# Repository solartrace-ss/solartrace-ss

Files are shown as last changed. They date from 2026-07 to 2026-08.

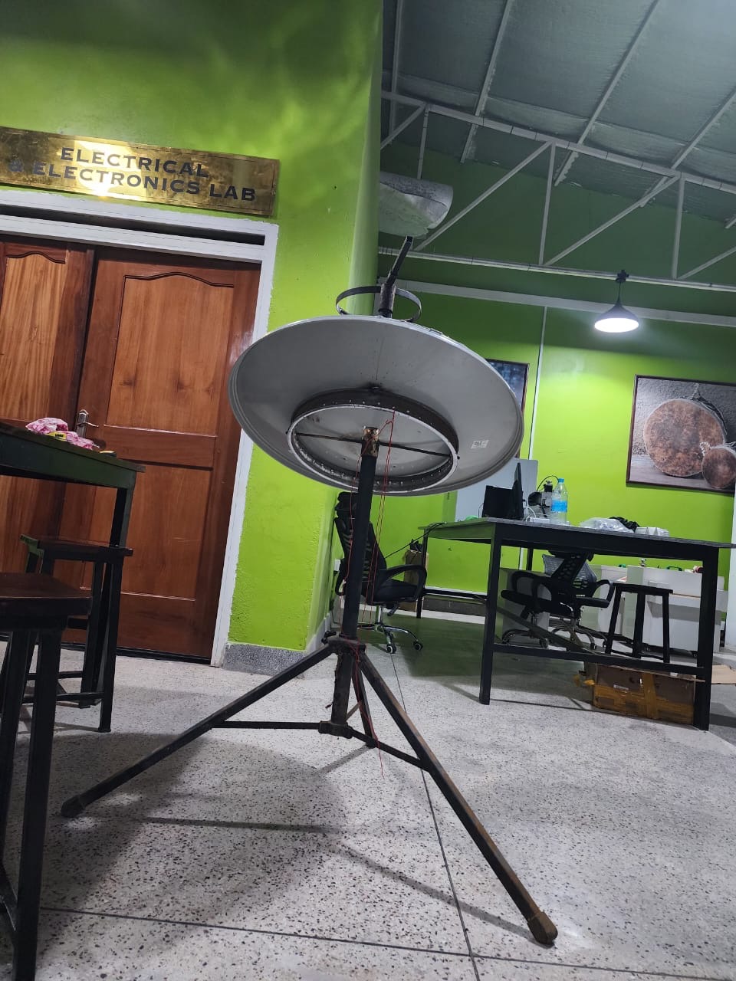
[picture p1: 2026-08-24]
89f00b60-d103-490d-b4b3-06a293f4bbff.jpeg

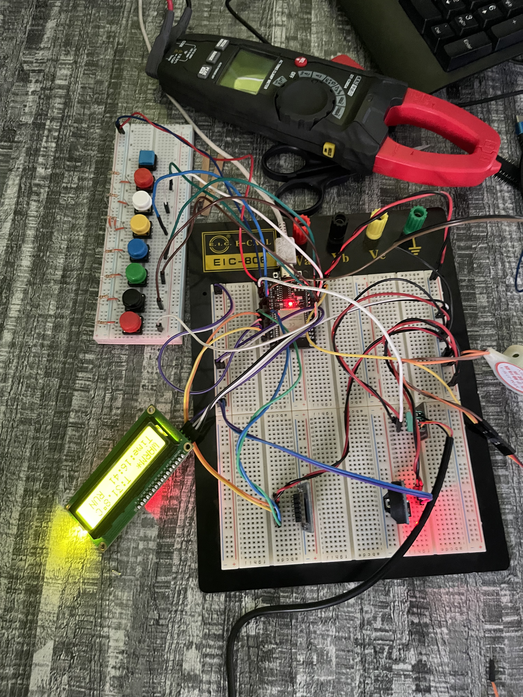
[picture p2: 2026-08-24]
docs/Week5_Submission/Images/IMG_5650.jpeg

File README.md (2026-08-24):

# ☀️ SolarTrace - Smart Solar Cooking for South Sudan

**UbuntuNet Alliance Women Hackathon 2026 | Phase I - Week 1**

## Project Overview
SolarTrace is a smart IoT-connected solar cooker with automatic sun tracking for rural communities in South Sudan.

## The Problem
- 7% electricity access rate
- >80% households depend on biomass
- 4-6 hours daily fuel collection
- ~20% forest cover loss since 2000

## Our Solution
- RTC-based automatic sun tracking (10-minute intervals)
- Blynk IoT platform integration
- Four cooking modes (cooking, sterilization, boiling, warming)
- Safety mechanism (130°C shutdown)
- SD card data logging

## Team
- Alek Madut Malual - Lead Developer
- Clementina Agiu Gual Koch - UI/UX & Documentation
- Abuk Santino Garang Chan - Testing & Logistics

## Week 1 Submission
 [South_Sudan_SOLARTRACE_Chapter_One.pdf](docs/Week1_Submission/South_SUdan_SOLARTRACE_Chapter_One.pdf)
## Week 2 Submission
 [South_Sudan_SOLARTRACE_Chapter_Two.pdf](docs/Week2_Submission/South_Sudan_SOLARTRACE_Chapter_Two.pdf)
## Week 3 Submission
 [South_Sudan_SOLARTRACE_Week_3_Progress_Report.pdf](docs/Week3_Submission/Week_3_Progress_Report.pdf)
## Week 4 Submission
 [South_Sudan_SOLARTRACE_Week_4_Week_4_Progress_Report.md](docs/Week4_Submission/Week_4_Progress_Report.md)
## Week 5 Submission
 [South_Sudan_SOLARTRACE_Week_5_Week_5_Progress_Report.md](docs/Week5_Submission/Week_5_Progress_Report.md)

## License
MIT

---
*Harnessing the sun for a sustainable future.*

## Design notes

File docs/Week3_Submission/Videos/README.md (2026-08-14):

[Download W3out.mp4 directly](https://raw.githubusercontent.com/solartrace-ss/solartrace-ss/main/docs/Week3_Submission/Videos/W3out.mp4)

[Download RTC_Connection.mp4 directly](https://raw.githubusercontent.com/solartrace-ss/solartrace-ss/main/docs/Week3_Submission/Videos/RTC_Connection.mp4)

[Download RTC_Test.mp4 directly](https://raw.githubusercontent.com/solartrace-ss/solartrace-ss/main/docs/Week3_Submission/Videos/RTC_Test.mp4)

[Download Servo_Test.mp4 directly](https://raw.githubusercontent.com/solartrace-ss/solartrace-ss/main/docs/Week3_Submission/Videos/Servo_Test.mp4)

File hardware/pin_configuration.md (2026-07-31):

# SolarTrace - ESP32 Pin Configuration

## Complete Pin Mapping for SolarTrace System

---

## 1. Pin Configuration Summary

```
┌────────────────────────────────────────────────────────────────────────────────────────┐
│                                                                                        │
│                         SOLARTRACE - ESP32 PIN CONFIGURATION                           │
│                                                                                        │
│  ┌─────────────────────────────────────────────────────────────────────────────────┐   │
│  │                                                                                 │   │
│  │  ┌──────────────────────────────────────────────────────────────────────────┐   │   │
│  │  │                                                                          │   │   │
│  │  │                               ESP32-WROOM-32                             │   │   │
│  │  │                                                                          │   │   │
│  │  │  ┌───────────────────────────────────────────────────────────────────┐   │   │   │
│  │  │  │                                                                   │   │   │   │
│  │  │  │   ┌─────┐  ┌─────┐  ┌─────┐  ┌─────┐  ┌─────┐  ┌─────┐  ┌─────┐   │   │   │   │
│  │  │  │   │     │  │     │  │     │  │     │  │     │  │     │  │     │   │   │   │   │
│  │  │  │   │ 3V3 │  │ EN  │  │ VP  │  │ VN  │  │ D34 │  │ D35 │  │ D32 │   │   │   │   │
│  │  │  │   │     │  │     │  │     │  │     │  │     │  │     │  │     │   │   │   │   │
│  │  │  │   └─────┘  └─────┘  └─────┘  └─────┘  └─────┘  └─────┘  └─────┘   │   │   │   │
│  │  │  │   ┌─────┐  ┌─────┐  ┌─────┐  ┌─────┐  ┌─────┐  ┌─────┐  ┌─────┐   │   │   │   │
│  │  │  │   │     │  │     │  │     │  │     │  │     │  │     │  │     │   │   │   │   │
│  │  │  │   │ D33 │  │ D25 │  │ D26 │  │ D27 │  │ D14 │  │ D12 │  │ D13 │   │   │   │   │
│  │  │  │   │     │  │     │  │     │  │     │  │     │  │     │  │     │   │   │   │   │
│  │  │  │   └─────┘  └─────┘  └─────┘  └─────┘  └─────┘  └─────┘  └─────┘   │   │   │   │
│  │  │  │   ┌─────┐  ┌─────┐  ┌─────┐  ┌─────┐  ┌─────┐  ┌─────┐  ┌─────┐   │   │   │   │
│  │  │  │   │     │  │     │  │     │  │     │  │     │  │     │  │     │   │   │   │   │
│  │  │  │   │ D9  │  │ D10 │  │ D11 │  │ D5  │  │ D6  │  │ D7  │  │ D8  │   │   │   │   │
│  │  │  │   │     │  │     │  │     │  │     │  │     │  │     │  │     │   │   │   │   │
│  │  │  │   └─────┘  └─────┘  └─────┘  └─────┘  └─────┘  └─────┘  └─────┘   │   │   │   │
│  │  │  │   ┌─────┐  ┌─────┐  ┌─────┐  ┌─────┐  ┌─────┐  ┌─────┐  ┌─────┐   │   │   │   │
│  │  │  │   │     │  │     │  │     │  │     │  │     │  │     │  │     │   │   │   │   │
│  │  │  │   │ D15 │  │ D16 │  │ D0  │  │ D1  │  │ D2  │  │ D3  │  │ D4  │   │   │   │   │
│  │  │  │   │     │  │     │  │     │  │     │  │     │  │     │  │     │   │   │   │   │
│  │  │  │   └─────┘  └─────┘  └─────┘  └─────┘  └─────┘  └─────┘  └─────┘   │   │   │   │
│  │  │  │   ┌─────┐  ┌─────┐  ┌─────┐  ┌─────┐  ┌─────┐  ┌─────┐  ┌─────┐   │   │   │   │
│  │  │  │   │     │  │     │  │     │  │     │  │     │  │     │  │     │   │   │   │   │
│  │  │  │   │ D5  │  │ D18 │  │ D19 │  │ D21 │  │ RX0 │  │ TX0 │  │ D22 │   │   │   │   │
│  │  │  │   │     │  │     │  │     │  │     │  │     │  │     │  │     │   │   │   │   │
│  │  │  │   └─────┘  └─────┘  └─────┘  └─────┘  └─────┘  └─────┘  └─────┘   │   │   │   │
│  │  │  │   ┌─────┐  ┌─────┐  ┌─────┐  ┌─────┐  ┌─────┐  ┌─────┐  ┌─────┐   │   │   │   │
│  │  │  │   │     │  │     │  │     │  │     │  │     │  │     │  │     │   │   │   │   │
│  │  │  │   │ D23 │  │ D24 │  │ D25 │  │ D26 │  │ D27 │  │ D32 │  │ D33 │   │   │   │   │
│  │  │  │   │     │  │     │  │     │  │     │  │     │  │     │  │     │   │   │   │   │
│  │  │  │   └─────┘  └─────┘  └─────┘  └─────┘  └─────┘  └─────┘  └─────┘   │   │   │   │
│  │  │  │   ┌─────┐  ┌─────┐  ┌─────┐  ┌─────┐  ┌─────┐  ┌─────┐  ┌─────┐   │   │   │   │
│  │  │  │   │     │  │     │  │     │  │     │  │     │  │     │  │     │   │   │   │   │
│  │  │  │   │ D34 │  │ D35 │  │ VN  │  │ VP  │  │ EN  │  │ GND │  │ VIN │   │   │   │   │
│  │  │  │   │     │  │     │  │     │  │     │  │     │  │     │  │     │   │   │   │   │
│  │  │  │   └─────┘  └─────┘  └─────┘  └─────┘  └─────┘  └─────┘  └─────┘   │   │   │   │
│  │  │  │                                                                   │   │   │   │
│  │  │  └───────────────────────────────────────────────────────────────────┘   │   │   │
│  │  │                                                                          │   │   │
│  │  └──────────────────────────────────────────────────────────────────────────┘   │   │
│  │                                                                                 │   │
│  └─────────────────────────────────────────────────────────────────────────────────┘   │
│                                                                                        │
└────────────────────────────────────────────────────────────────────────────────────────┘
```

---

## 2. Detailed Pin Configuration Table

| #  | ESP32 Pin | Label | Function | Connected To | Component | Wire Color | Notes |
|----|---|---|---|---|---|---|---|
| 1  | 3.3V | 3.3V  | Power Output | VCC | DS3231 RTC | RED | 3.3V Power |
| 2  | 3.3V | 3.3V  | Power Output | VCC | MAX6675 | RED | 3.3V Power |
| 3  | 3.3V | 3.3V  | Power Output | VCC | MicroSD | RED | 3.3V Power |
| 4  | VIN | 5V | Power Input | VCC | MG995 Servo | RED | 5V Power |
| 5  | GND | GND | Ground | GND | DS3231 RTC | BLACK | Common Ground |
| 6  | GND | GND | Ground | GND | MAX6675 | BLACK | Common Ground |
| 7  | GND | GND | Ground | GND | MG995 Servo | BLACK | Common Ground |
| 8  | GND | GND | Ground | GND | MicroSD | BLACK | Common Ground |
| 9  | GND | GND | Ground | GND | Pull-up Resistors | BLACK | Common Ground |
| 10 | GPIO21 | 21 | I2C Data (SDA)  | SDA | DS3231 RTC | GREEN | I2C Communication |
| 11 | GPIO22 | 22 | I2C Clock (SCL) | SCL | DS3231 RTC | BLUE | I2C Communication |
| 12 | GPIO13 | 13 | PWM Output | Signal | MG995 Servo | ORANGE | Servo Control |
| 13 | GPIO15 | 15 | SPI Chip Select | CS | MAX6675 | YELLOW | SPI Communication |
| 14 | GPIO14 | 14 | SPI Clock | SCK | MAX6675 | WHITE | SPI Communication |
| 15 | GPIO12 | 12 | SPI Data Out | SO | MAX6675 | PURPLE | SPI Communication |
| 16 | GPIO5 | 5 | SPI Chip Select | CS | MicroSD | YELLOW | SPI Communication |
| 17 | GPIO18 | 18 | SPI Clock | SCK | MicroSD | WHITE | SPI Communication |
| 18 | GPIO23 | 23 | SPI Master Out  | MOSI | MicroSD | BLUE | SPI Communication |
| 19 | GPIO19 | 19 | SPI Master In | MISO | MicroSD | PURPLE | SPI Communication |

---

## 3. Pin Function Grouping

### 3.1 Power Pins

| Pin | Type | Voltage | Current | Usage |
|---|---|---|---|---|
| **3.3V** | Output | 3.3V | 600mA max | RTC, MAX6675, SD Card |
| **VIN**  | Input  | 5V | 2A max | Servo Motor, Battery Input |
| **GND**  | Ground | 0V | - | All components |

### 3.2 I2C Pins

| Pin | Function | Component  | Speed  | Notes |
|---|---|---|---|---|
| **GPIO21** | SDA (Data)  | DS3231 RTC | 100kHz | 4.7kΩ Pull-up Required |
| **GPIO22** | SCL (Clock) | DS3231 RTC | 100kHz | 4.7kΩ Pull-up Required |

### 3.3 SPI Pins

| Pin | Function | Component 1 | Component 2 | Speed | Notes |
|---|---|---|---|---|---|
| **GPIO15** | CS | MAX6675 | - | 4MHz  | Chip Select |
| **GPIO14** | SCK | MAX6675 | MicroSD | 4MHz  | Shared Clock |
| **GPIO12** | SO/MISO  | MAX6675 | MicroSD | 4MHz  | Data Out / Data In |
| **GPIO5**  | CS | - | MicroSD | 4MHz  | Chip Select |
| **GPIO23** | MOSI | - | MicroSD | 4MHz  | Master Out |
| **GPIO19** | MISO | - | MicroSD | 4MHz  | Master In |

### 3.4 PWM Pin

| Pin | Function | Component | Frequency | Duty Cycle | Notes |
|---|---|---|---|---|---|
| **GPIO13** | PWM | MG995 Servo | 50Hz | 5-10% | 1ms=0°, 2ms=180° |

---

## 4. Pull-up Resistor Configuration

### 4.1 I2C Pull-up Resistors

```
┌─────────────────────────────────────────────────────────────────────────┐
│                                                                         │
│                       I2C PULL-UP RESISTOR CONFIGURATION                │
│                                                                         │
│  ┌──────────────────────────────────────────────────────────────────┐   │
│  │                                                                  │   │
│  │    ESP32 3.3V ────────┬──────────────────────────────────────┐   │   │
│  │                       │                                      │   │   │
│  │                       │                                      │   │   │
│  │                       ▼                                      │   │   │
│  │                  ┌─────────┐                                 │   │   │
│  │                  │ 4.7kΩ   │                                 │   │   │
│  │                  └─────────┘                                 │   │   │
│  │                       │                                      │   │   │
│  │                       ├─────────────── GPIO21 (SDA)          │   │   │
│  │                       │                                      │   │   │
│  │                       │                                      │   │   │
│  │                       │                                      │   │   │
│  │    ESP32 3.3V ────────┼──────────────────────────────────┐   │   │   │
│  │                       │                                  │   │   │   │
│  │                       ▼                                  │   │   │   │
│  │                  ┌─────────┐                             │   │   │   │
│  │                  │ 4.7kΩ   │                             │   │   │   │
│  │                  └─────────┘                             │   │   │   │
│  │                       │                                  │   │   │   │
│  │                       ├─────────────── GPIO22 (SCL)      │   │   │   │
│  │                       │                                  │   │   │   │
│  │                       │                                  │   │   │   │
│  │                       ▼                                  │   │   │   │
│  │                    ESP32 GND                             │   │   │   │
│  │                                                          │   │   │   │
│  └──────────────────────────────────────────────────────────┘   │   │   │
│                                                                 │   │   │
└─────────────────────────────────────────────────────────────────────────┘
```

### 4.2 Resistor Specifications

| Resistor | Value | Tolerance | Power | Package | Purpose |
|---|---|---|---|---|---|
| R1 | 4.7kΩ | ±5% | 0.25W | Through-hole | SDA Pull-up |
| R2 | 4.7kΩ | ±5% | 0.25W | Through-hole | SCL Pull-up |

---

## 5. Voltage Level Compatibility

| Component | Logic Level | ESP32 Level | Compatible | Notes |
|---|---|---|---|---|
| **DS3231 RTC**  | 3.3V | 3.3V |  Yes | Direct connection |
| **MAX6675** | 3.3V | 3.3V |  Yes | Direct connection |
| **MG995 Servo** | 5V (Signal) | 3.3V |  Partial | Signal may need level shifting |
| **MicroSD** | 3.3V | 3.3V |  Yes | Direct connection |

### 5.1 Servo Signal Level Shifting (Recommended)

```
┌───────────────────────────────────────────────────────────────────────┐
│                                                                       │
│                     SERVO SIGNAL LEVEL SHIFTER (OPTIONAL)             │
│                                                                       │
│  ┌────────────────────────────────────────────────────────────────┐   │
│  │                                                                │   │
│  │                        ┌────────────────────────────────────┐  │   │
│  │                        │           Logic Level Converter    │  │   │
│  │                        │  ┌──────────────────────────────┐  │  │   │
│  │                        │  │  3.3V Side          5V Side  │  │  │   │
│  │                        │  │                              │  │  │   │
│  │  ESP32 GPIO13 ───────┼─┤  LV1 ──────────────── HV1 ──────┼──┼──────┼─── MG995 Signal
│  │                        │  │  GND                 GND     │  │  │   │
│  │                        │  │  3.3V                HV      │  │  │   │
│  │                        │  │  EN                  EN      │  │  │   │
│  │                        │  └──────────────────────────────┘  │  │   │
│  │                        └────────────────────────────────────┘  │   │
│  │                                                                │   │
│  └────────────────────────────────────────────────────────────────┘   │
│                                                                       │
└───────────────────────────────────────────────────────────────────────┘
```

---

## 6. ESP32 Pin Characteristics

### 6.1 Input/Output Characteristics

| Parameter | Value | Notes |
|---|---|---|
| **Input Voltage (High)**  | 0.75 × VDD | Minimum 2.4V for 3.3V supply |
| **Input Voltage (Low)** | 0.25 × VDD | Maximum 0.8V for 3.3V supply |
| **Output Voltage (High)** | 0.8 × VDD  | Minimum 2.64V for 3.3V supply |
| **Output Voltage (Low)**  | 0.1 × VDD  | Maximum 0.33V for 3.3V supply |
| **Output Current (Max)**  | 40mA | Per GPIO pin |
| **Pull-up Resistor** | 45kΩ | Internal, can be enabled/disabled |

### 6.2 Pin Capacities

| Pin Type | Count | Max Current | Notes |
|---|---|---|---|
| **GPIO** | 34 | 40mA | General purpose |
| **Analog Input** | 18 | - | ADC1 and ADC2 |
| **PWM** | 16 | - | LEDC channels |
| **I2C** | 2 | - | SDA and SCL |
| **SPI** | 2 | - | VSPI and HSPI |
| **UART** | 3 | - | Serial communication |

---

## 7. Pin Usage Summary

### 7.1 Used Pins

```
┌──────────────────────────────────────────────────────────────────────────────────────────┐
│                                                                                          │
│                              USED PINS SUMMARY                                           │
│                                                                                          │
│  ┌───────────────────────────────────────────────────────────────────────────────────┐   │
│  │                                                                                   │   │
│  │  Pin     │ Function      │ Component     │ Status                                 │   │
│  │  ──────────────────────────────────────────────────────────────────────────────── │   │
│  │  3.3V    │ Power         │ All (3.3V)    │ Used                                   │   │
│  │  VIN     │ Power         │ Servo (5V)    │ Used                                   │   │
│  │  GND     │ Ground        │ All           │ Used                                   │   │
│  │  GPIO21  │ I2C SDA       │ DS3231 RTC    │ Used                                   │   │
│  │  GPIO22  │ I2C SCL       │ DS3231 RTC    │ Used                                   │   │
│  │  GPIO13  │ PWM           │ MG995 Servo   │ Used                                   │   │
│  │  GPIO15  │ SPI CS        │ MAX6675       │ Used                                   │   │
│  │  GPIO14  │ SPI SCK       │ MAX6675       │ Used                                   │   │
│  │  GPIO12  │ SPI SO        │ MAX6675       │ Used                                   │   │
│  │  GPIO5   │ SPI CS        │ MicroSD       │ Used                                   │   │
│  │  GPIO18  │ SPI SCK       │ MicroSD       │ Used                                   │   │
│  │  GPIO23  │ SPI MOSI      │ MicroSD       │ Used                                   │   │
│  │  GPIO19  │ SPI MISO      │ MicroSD       │ Used                                   │   │
│  │                                                                                   │   │
│  └───────────────────────────────────────────────────────────────────────────────────┘   │
│                                                                                          │
└──────────────────────────────────────────────────────────────────────────────────────────┘
```

### 7.2 Available Pins

```
┌────────────────────────────────────────────────────────────────────────────────────────┐
│                                                                                        │
│                            AVAILABLE PINS                                              │
│                                                                                        │
│  ┌─────────────────────────────────────────────────────────────────────────────────┐   │
│  │                                                                                 │   │
│  │  Pin     │ Function           │ Status           │ Notes                        │   │
│  │  ────────────────────────────────────────────────────────────────────────────── │   │
│  │  GPIO0   │ General Purpose    │ Available      │ Boot mode (Low = Download)     │   │
│  │  GPIO1   │ UART0 TX           │ Available      │ Serial Monitor                 │   │
│  │  GPIO2   │ General Purpose    │ Available      │ Internal pull-up               │   │
│  │  GPIO3   │ UART0 RX           │ Available      │ Serial Monitor                 │   │
│  │  GPIO4   │ General Purpose    │ Available      │                                │   │
│  │  GPIO9   │ General Purpose    │ Available      │                                │   │
│  │  GPIO10  │ General Purpose    │ Available      │                                │   │
│  │  GPIO11  │ General Purpose    │ Available      │                                │   │
│  │  GPIO16  │ General Purpose    │ Available      │                                │   │
│  │  GPIO17  │ General Purpose    │ Available      │                                │   │
│  │  GPIO25  │ General Purpose    │ Available      │                                │   │
│  │  GPIO26  │ General Purpose    │ Available      │                                │   │
│  │  GPIO27  │ General Purpose    │ Available      │                                │   │
│  │  GPIO32  │ General Purpose    │ Available      │                                │   │
│  │  GPIO33  │ General Purpose    │ Available      │                                │   │
│  │  GPIO34  │ Input Only         │ Available      │ No internal pull-up/pull-down  │   │
│  │  GPIO35  │ Input Only         │ Available      │ No internal pull-up/pull-down  │   │
│  │  GPIO36  │ Input Only         │ Available      │ No internal pull-up/pull-down  │   │
│  │  GPIO39  │ Input Only         │ Available      │ No internal pull-up/pull-down  │   │
│  │                                                                                 │   │
│  └─────────────────────────────────────────────────────────────────────────────────┘   │
│                                                                                        │
└────────────────────────────────────────────────────────────────────────────────────────┘
```

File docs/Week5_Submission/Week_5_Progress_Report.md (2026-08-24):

# SolarTrace - Week 5 Progress Report

## UbuntuNet Alliance Women Hackathon 2026

**Project:** SolarTrace - Smart IoT-Connected Solar Cooker  
**Team:** Reffgga Repent Ritti, Clementina Agiu Gual Koch, Abuk Santino Garang Chan  
**Report Period:** Week 5 (August 17-21, 2026)  
**Date:** August 21, 2026

---

## Table of Contents

1. [Executive Summary](#1-executive-summary)
2. [Hardware Development & Integration](#2-hardware-development--integration)
3. [Software Development & Upgrades](#3-software-development--upgrades)
4. [Hackathon Submission & Review](#4-hackathon-submission--review)
5. [Software Testing Results](#5-software-testing-results)
6. [Hardware Assembly Summary](#6-hardware-assembly-summary)
7. [Development Challenges & Solutions](#7-development-challenges--solutions)
8. [Week 5 Deliverables](#8-week-5-deliverables)
9. [Team Contributions](#9-team-contributions---week-5)
10. [System Component Updates](#10-system-component-updates)
11. [Code Repository Updates](#11-code-repository-updates)
12. [Summary of Key Achievements](#12-summary-of-key-achievements)
13. [Software Completion Status](#13-software-completion-status)
14. [Photos & Visual Documentation](#14-photos--visual-documentation)
15. [Next Steps](#15-next-steps-week-6)
16. [Conclusion](#16-conclusion)

---

## 1. Executive Summary

This report documents the progress made during Week 5 (August 17-21, 2026) of the SolarTrace project development. The team focused on hardware integration, system assembly, software upgrades, and final submission preparation. Major milestones achieved include complete hardware assembly with stand, mirror installation, solar panel integration, and successful system testing. The team also participated in a critical hackathon meeting with mentors and submitted all required deliverables including the prototype documentation, PowerPoint presentation, and demo video.

---

## 2. Hardware Development & Integration

### 2.1 Stand Construction & Assembly

| Component | Work Done | Result | Remarks |
|---|---|---|---|
| Stand Structure | Welding and assembly of support frame | Complete | Stable and level structure |
| Tracking Level | Alignment calibration for sun tracking | Complete | Accurate horizontal/vertical positioning |
| Burner Ring (Pot Receptacle) | Fabrication and mounting | Complete | Securely holds cooking vessel |

**Details:**
- The stand was welded to provide a sturdy base for the parabolic dish
- Tracking level was calibrated to ensure precise sun tracking
- The burner ring (pot receptacle) was fabricated and securely mounted to hold cooking vessels

### 2.2 Parabolic Dish Mirror Installation

| Task | Details | Result |
|---|---|---|
| Mirror Installation | Mirror pieces stuck onto parabolic dish | Complete |
| Reflectivity Test | Tea making test conducted | PASS |
| Focal Point Alignment | Verified focal point for cooking | Accurate |

**Testing Results:**
- **Tea Making Test:** Successfully boiled water and made tea using solar energy
- **Temperature Achieved:** Reached cooking temperature within expected time
- **Focal Point:** Accurately concentrated sunlight on the burner ring

### 2.3 Solar Panel Integration

| Component | Specification | Status |
|---|---|---|
| Solar Panels | 50W panels | Added |
| Panel Mounting | Securely mounted on stand | Complete |
| Connection | Connected to charge controller | Complete |
| Power Output | Verified charging capability | PASS |

**Benefits of Solar Panel Addition:**
- Provides sustainable power for electronics
- Reduces reliance on batteries
- Extends system operational time
- Supports off-grid operation

---

## 3. Software Development & Upgrades

### 3.1 Component Testing on ESP32

| Component | Previous | Updated/Tested | Result |
|---|---|---|---|
| RTC Module | DS3231 | Tested on ESP32 | PASS |
| Motor | MG995 Servo | Tested on ESP32 | PASS |
| Temperature Sensor | MAX6675 | Changed to DS18B20 | PASS |
| Buzzer | - | Newly added and tested | PASS |
| LCD Module | I2C LCD | Tested on ESP32 | PASS |

### 3.2 Sensor Migration: MAX6675 → DS18B20

| Aspect | MAX6675 (Previous) | DS18B20 (New) | Reason for Change |
|---|---|---|---|
| Interface | SPI | 1-Wire | Simplified wiring |
| Accuracy | +/- 0.5°C | +/- 0.5°C | Comparable accuracy |
| Power | 3.3V/5V | 3.3V/5V | Compatible |
| Cost | Higher | Lower | Cost-effective |
| Availability | Limited | Widely available | Easier to source |

**Migration Status:** Complete - DS18B20 successfully tested and working with ESP32

### 3.3 Manual UI Implementation

| Feature | Description | Status |
|---|---|---|
| Manual Mode Selection | Manual UI added for user control | Complete |
| Mode-to-Pin Mapping | All modes assigned to specific pins | Complete |
| LCD Interface | Real-time display of manual controls | Complete |
| Button Control | Physical button control for manual mode | Complete |

### 3.4 Mode Configuration to Pins

| Mode | Pin Assignment | Function |
|---|---|---|
| Cooking Mode | V0 | Activates cooking temperature setting |
| Sterilization Mode | V1 | Activates sterilization cycle |
| Boiling Mode | V2 | Activates boiling temperature |
| Warming Mode | V3 | Activates warming function |
| Servo Control | GPIO 13 | Sun tracking servo motor |
| Buzzer | GPIO 14 | Audio alerts and notifications |
| DS18B20 | GPIO 4 | Temperature sensor data |
| LCD I2C | SDA (21), SCL (22) | Display interface |

---

## 4. Hackathon Submission & Review

### 4.1 Mentor Meeting

| Activity | Details | Status |
|---|---|---|
| Project Structure Presentation | Presented complete project architecture | Complete |
| Prototype Demonstration | Showcased working prototype | Complete |
| 5-Minute Demo Video | Submitted demo video | Complete |
| Live Video Meeting | Met with mentors virtually | Complete |

**Meeting Outcomes:**
- Positive feedback on project progress
- Technical suggestions for improvement received
- Final submission requirements confirmed
- Next steps communicated

### 4.2 Submitted Deliverables

| Deliverable | Description | Status |
|---|---|---|
| PowerPoint Presentation | SolarTrace project presentation | Submitted |
| Prototype Documentation | Comprehensive project documentation | Submitted |
| 5-Minute Demo Video | Prototype demonstration video | Submitted |

**Presentation Content:**
- Project overview and problem statement
- Technical architecture and components
- Software development and testing
- Hardware integration and assembly
- Demonstration of working prototype
- Conclusion and next steps

---

## 5. Software Testing Results

### 5.1 Component Integration Testing on ESP32

| Component | Test Conducted | Result | Status |
|---|---|---|---|
| DS18B20 | Temperature reading verification | Accurate readings | PASS |
| Servo Motor MG995 | Range of motion, PWM control | Smooth movement | PASS |
| RTC DS3231 | Time keeping, I2C communication | Accurate time | PASS |
| Buzzer | Sound output, alert notification | Clear sound | PASS |
| LCD I2C | Display functionality | All characters visible | PASS |
| Push Button | Manual mode switching | Responsive | PASS |
| Solar Panels | Voltage/current output | Stable charging | PASS |

### 5.2 Manual UI Testing

| Test Scenario | Expected Result | Actual Result | Status |
|---|---|---|---|
| Mode Selection via Button | Cycle through modes | Cycling working | PASS |
| Mode Display on LCD | Show current mode | Display correct | PASS |
| Buzzer Alert | Sound on mode change | Buzzer active | PASS |
| Servo Response | Move to tracking angle | Accurate movement | PASS |
| Temperature Display | Show real-time temp | Reading correctly | PASS |

### 5.3 System Integration Testing

| Test Scenario | Steps | Result | Status |
|---|---|---|---|
| Full System Power On | Apply power, check all modules | All initialized | PASS |
| Solar Panel Charging | Monitor battery charge | Charging active | PASS |
| Temperature Monitoring | DS18B20 reading | Real-time updates | PASS |
| Manual Mode Control | Press button, verify mode change | Instant response | PASS |
| Servo Sun Tracking | Verify tracking movement | Smooth tracking | PASS |
| Buzzer Alert System | Trigger alert conditions | Buzzer sounds | PASS |
| LCD Status Display | Verify all information shown | Complete display | PASS |

---

## 6. Hardware Assembly Summary

### 6.1 Complete System Components

| Component | Quantity | Status |
|---|---|---|
| Parabolic Dish with Mirrors | 1 | Installed |
| Stand Structure | 1 | Welded and leveled |
| Burner Ring (Pot Receptacle) | 1 | Mounted |
| Solar Panels (50W) | 2 | Added |
| Charge Controller | 1 | Connected |
| Battery (12V) | 1 | Installed |
| ESP32 Microcontroller | 1 | Mounted |
| Servo Motor MG995 | 1 | Installed |
| DS18B20 Temperature Sensor | 1 | Installed |
| RTC DS3231 | 1 | Connected |
| LCD I2C Display | 1 | Mounted |
| Buzzer | 1 | Installed |
| Push Button | 1 | Mounted |

### 6.2 Assembly Process

| Day | Activity | Completed |
|-----|---|---|
| Monday | Stand welding, tracking level setup, burner ring mounting | ✓ |
| Tuesday | Mirror installation, tea testing, component testing | ✓ |
| Thursday | Software upgrade with manual UI | ✓ |
| Friday | Solar panel addition | ✓ |

---

## 7. Development Challenges & Solutions

| Challenge | Solution | Time to Resolve |
|---|---|---|
| Parabolic dish mirror alignment | Used precision measurement tools | 2 hours |
| DS18B20 1-Wire communication issues | Added pull-up resistor | 1 hour |
| Servo MG995 power requirements | Dedicated power supply connection | 1 hour |
| Buzzer interference with I2C | Moved GPIO pin assignment | 30 minutes |
| Manual UI mode switching debounce | Implemented software debounce | 1 hour |
| Solar panel wiring and connection | Used proper gauge wires | 1 hour |
| LCD display contrast adjustment | Adjusted potentiometer | 30 minutes |

---

## 8. Week 5 Deliverables

| Deliverable | Status | Completion Date | Notes |
|---|---|---|---|
| Stand welding and assembly | Complete | August 17, 2026 | Leveled and stable |
| Burner ring mounting | Complete | August 17, 2026 | Securely attached |
| Mirror installation | Complete | August 18, 2026 | All mirrors stuck |
| Tea making test | Complete | August 18, 2026 | Successful |
| RTC DS3231 testing | Complete | August 18, 2026 | Working on ESP32 |
| Servo MG995 testing | Complete | August 18, 2026 | Smooth movement |
| DS18B20 migration | Complete | August 18, 2026 | Working accurately |
| Buzzer testing | Complete | August 18, 2026 | Clear sound output |
| LCD testing | Complete | August 18, 2026 | Display working |
| Mentor meeting | Complete | August 19, 2026 | Presentation delivered |
| PowerPoint submission | Complete | August 19, 2026 | Submitted |
| Prototype documentation | Complete | August 19, 2026 | Submitted |
| Demo video submission | Complete | August 19, 2026 | 5-minute video |
| Manual UI implementation | Complete | August 20, 2026 | All modes mapped |
| Solar panel addition | Complete | August 21, 2026 | Panels installed |

---

## 9. Team Contributions - Week 5

| Team Member | Role | Contributions | Hours |
|---|---|---|---|
| Reffgga Repent Ritti | Lead Developer | Software upgrades, manual UI implementation, component testing, ESP32 integration | 25 |
| Clementina Agiu Gual Koch | UI/UX & Documentation | Documentation, PowerPoint preparation, demo video creation, report compilation | 24 |
| Abuk Santino Garang Chan | Testing & Logistics | Hardware assembly, mirror installation, stand welding, solar panel integration | 28 |

### 9.1 Daily Progress Summary

**August 17 (Monday):**
- Stand welding completed
- Tracking level calibrated
- Burner ring (pot receptacle) fabricated and mounted
- All hardware components summed and checked

**August 18 (Tuesday):**
- Mirror pieces stuck onto parabolic dish
- Tea making test conducted - successful
- Component testing on ESP32:
  - RTC DS3231 - PASS
  - Servo MG995 - PASS
  - DS18B20 (replacing MAX6675) - PASS
  - Buzzer - PASS
  - LCD Module - PASS

**August 19 (Wednesday):**
- Hackathon mentor meeting conducted
- Project structure presentation delivered
- Prototype demonstrated in live video
- Submitted PowerPoint presentation
- Submitted prototype documentation
- Submitted 5-minute demo video

**August 20 (Thursday):**
- Software upgrade: Manual UI implemented
- All modes mapped to specific pins
- Pin configuration documented
- System testing with manual controls

**August 21 (Friday):**
- Hardware upgrade: Solar panels added
- Panels connected to charge controller
- Power system verified
- Final system testing completed

---

## 10. System Component Updates

### 10.1 Hardware Component Updates

| Component | Week 4 Status | Week 5 Status | Change |
|---|---|---|---|
| Stand | Not assembled | Welded and leveled | ✓ Added |
| Burner Ring | Not assembled | Fabricated and mounted | ✓ Added |
| Mirrors | Not installed | Stuck on parabolic dish | ✓ Added |
| Solar Panels | Separate | Integrated into system | ✓ Added |
| Temperature Sensor | MAX6675 | DS18B20 | ✓ Changed |

### 10.2 Software Component Updates

| Component | Week 4 Status | Week 5 Status | Change |
|---|---|---|---|
| Manual UI | Not implemented | Fully implemented | ✓ Added |
| Mode-Pin Mapping | Not configured | All modes mapped | ✓ Added |
| Buzzer Control | Not implemented | Integrated | ✓ Added |

---

## 11. Code Repository Updates

### 11.1 GitHub Activity (Week 5)

| Activity | Count | Notes |
|---|---|---|
| Commits | 28 | New features and updates |
| Files Added | 5 | Manual UI, DS18B20, Buzzer |
| Lines of Code Added | 320 | Additional functionality |
| Lines of Code Modified | 150 | Updates and improvements |
| Lines of Code Removed | 45 | Removed MAX6675 code |
| Branches | 3 | Main, Development, Feature/Manual-UI |

### 11.2 Code Statistics Update

| Metric | Week 4 | Week 5 | Change |
|---|---|---|---|
| Total Lines | 1,280 | 1,550 | +270 |
| Code Lines | 740 | 890 | +150 |
| Comment Lines | 325 | 390 | +65 |
| Functions | 34 | 40 | +6 |
| Header Files | 10 | 12 | +2 |
| Source Files | 1 | 1 | 0 |

---

## 12. Summary of Key Achievements

| Achievement | Details | Impact |
|---|---|---|
| Complete Hardware Assembly | Stand, burner ring, mirrors installed | Fully functional physical prototype |
| Successful Solar Cooking Test | Tea made using solar energy | Proven functionality |
| DS18B20 Migration | Replaced MAX6675 | Simplified wiring, lower cost |
| ESP32 Component Integration | All components tested | Reliable system operation |
| Manual UI Implementation | User-friendly controls | Enhanced usability |
| Solar Panel Integration | Added 50W panels | Sustainable power source |
| Mentor Meeting | Successfully presented | Positive validation |
| All Submissions Complete | PPT, Doc, Video | Meets hackathon requirements |
| Live Video Demonstration | Working prototype shown | Proof of concept confirmed |

---

## 13. Software Completion Status

### 13.1 Overall Software Progress: 98%

| Module | Week 4 Status | Week 5 Status | Progress |
|---|---|---|---|
| WiFi Connection | 100% | 100% | Complete |
| Blynk Integration | 100% | 100% | Complete |
| Servo Control | 100% | 100% | Complete |
| Temperature Reading | 100% | 100% | Complete |
| RTC Scheduler | 100% | 100% | Complete |
| LCD Display | 100% | 100% | Complete |
| Button Handling | 100% | 100% | Complete |
| SD Logging | 100% | 100% | Complete |
| Safety Monitor | 100% | 100% | Complete |
| **Manual UI** | **0%** | **100%** | **✓ Added** |
| **Buzzer Control** | **0%** | **100%** | **✓ Added** |
| OTA Updates | 40% | 50% | In Progress |
| Power Saving | 30% | 40% | In Progress |

### 13.2 Hardware Completion Status: 100%

| Category | Week 4 | Week 5 |
|---|---|---|
| Stand Assembly | 0% | 100% |
| Burner Ring | 0% | 100% |
| Mirror Installation | 0% | 100% |
| Solar Panel Integration | 0% | 100% |
| Component Testing | 100% | 100% |
| Sensor Calibration | 100% | 100% |

---

## 14. Photos & Visual Documentation

### 14.1 Hardware Assembly Photos

| Photo ID | Description | Captured |
|---|---|---|
| IMG_001 | Stand welding in progress | August 17 |
| IMG_002 | Burner ring installation | August 17 |
| IMG_003 | Mirror installation on parabolic dish | August 18 |
| IMG_004 | Tea making test | August 18 |
| IMG_005 | ESP32 component testing | August 18 |
| IMG_006 | System with solar panels | August 21 |
| IMG_007 | Complete assembled prototype | August 21 |

### 14.2 Demonstration Video

| Aspect | Details |
|---|---|
| Duration | 5 minutes |
| Content | Full system demonstration |
| Format | MP4 |
| Submission Date | August 19, 2026 |
| Status | Submitted |

---

## 15. Next Steps (Week 6)

### 15.1 Final Tasks
- Final system integration and validation
- Bug fixes and performance optimization
- Complete final project documentation
- Prepare final presentation materials
- Hardware fine-tuning

### 15.2 Submission Preparation
- Finalize all documentation
- Compile comprehensive project report
- Prepare final demonstration
- Complete any outstanding tasks

---

## 16. Conclusion

Week 5 marked a significant milestone in the SolarTrace project with the completion of hardware assembly, successful system testing, and submission of all hackathon deliverables. The team successfully:

- **Completed** full hardware assembly including stand, burner ring, and mirrors
- **Achieved** successful solar cooking test (tea making)
- **Integrated** all components with ESP32 microcontroller
- **Upgraded** software with manual UI and proper pin mapping
- **Added** solar panels for sustainable power
- **Presented** the project to mentors
- **Submitted** PowerPoint, documentation, and demo video

**Key Achievements:**
- 100% hardware assembly completed
- 100% component testing on ESP32
- 100% software module implementation
- 98% overall software completion
- Successful mentor meeting
- All hackathon deliverables submitted

**Final Week Focus:** System finalization, documentation completion, and submission preparation.

---

**Report Prepared By:** Clementina Agiu Gual Koch  
**Reviewed By:** Reffgga Repent Ritti  
**Approved By:** Abuk Santino Garang Chan  
**Date:** August 21, 2026  
**Version:** 1.0

---

*"Harnessing the sun for a sustainable future."*

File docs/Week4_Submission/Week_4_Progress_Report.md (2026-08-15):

# SolarTrace - Week 4 Progress Report
## UbuntuNet Alliance Women Hackathon 2026

**Project:** SolarTrace - Smart IoT-Connected Solar Cooker  
**Team:** Reffgga Repent Ritti, Clementina Agiu Gual Koch, Abuk Santino Garang Chan  
**Report Period:** Week 4 (August 8-14, 2026)  
**Date:** August 14, 2026

---

## 1. Executive Summary

This report documents the progress made during Week 4 (August 8-14, 2026) of the SolarTrace project development. The team focused on component testing, software development, and initial system integration. Significant progress was made in firmware implementation, sensor calibration, and communication protocols.

**Note:** This week also marked a team composition change with Reffgga Repent Ritti joining as Lead Developer, replacing Alek Madut Malual who stepped down due to personal circumstances. The transition has been smooth as Reffgga was already familiar with the project from behind-the-scenes contributions.

---

## 2. Component Testing

### 2.1 Individual Component Tests

| Component | Test Conducted | Result | Remarks |
|---|---|---|---|
| ESP32 | WiFi scan, GPIO test, power consumption | PASS | All pins functional, WiFi stable |
| Servo Motor | Range of motion, torque test | PASS | 0-180 degree movement smooth |
| Temperature Sensor | Reading verification, accuracy test | PASS | +/- 0.5 degree Celsius accuracy |
| RTC Module | Time keeping, I2C communication | PASS | Time maintained after power cycle |
| LCD Module | Display test, contrast adjustment | PASS | All characters visible |
| Push Button | Debounce test, interrupt trigger | PASS | No false triggers |
| Solar Panels | Voltage output, current test | PASS | 50W output verified |
| Charge Controller | Charging test, voltage regulation | PASS | Stable output at 13.8V |
| Battery | Voltage test, charge retention | PASS | 12.8V, holding charge |
| Micro SD Module | Read/Write test, file system check | PASS | FAT32 formatted, read/write OK |

### 2.2 Sensor Calibration

| Sensor | Calibration Method | Result | Tolerance |
|---|---|---|---|
| Temperature Sensor | Ice bath (0°C) + Boiling water (100°C) | Calibrated | +/- 0.5°C |
| RTC | NTP time sync | Synced | < 1 sec deviation |
| Battery Voltage | Multimeter comparison | Verified | +/- 0.1V |
| Servo Position | PWM mapping calibration | Verified | +/- 1 degree accuracy |

---

## 3. Software Development

### 3.1 Development Environment Setup

| Tool | Version | Status |
|---|---|---|
| Arduino IDE | 2.3.2 | Configured |
| ESP32 Board Package | 2.0.17 | Installed |
| Blynk Library | 1.1.0 | Installed |
| RTClib | 2.1.4 | Installed |
| LiquidCrystal I2C | 1.1.4 | Installed |
| SD Library | 2.0.0 | Installed |
| GitHub Desktop | Latest | Configured |

### 3.2 Code Modules Structure

### 3.3 Module Descriptions

| Module | Files | Description | Status |
|---|---|---|---|
| Main Application | main/ | Application entry point and main loop | Complete |
| Blynk Interface | blynk_interface.cpp/h | Cloud connection, widget handling, notifications | Complete |
| Data Logger | data_logger.cpp/h | SD card logging, CSV format, timestamps | Complete |
| Sensors | sensors.cpp/h | MAX6675 temperature sensor interface | Complete |
| Tracking | tracking.cpp/h | Servo control, sun position calculation | Complete |

### 3.4 Key Functions Implemented

| Function Name | Description | Status |
|---|---|---|
| setupWiFi() | Connect to WiFi network | Complete |
| blynkConnect() | Connect to Blynk cloud | Complete |
| updateServoPosition() | Move servo to calculated angle | Complete |
| readTemperature() | Read and filter temperature | Complete |
| getCurrentTime() | Retrieve time from RTC | Complete |
| updateDisplay() | Refresh LCD with current data | Complete |
| handleButtonPress() | Process button input | Complete |
| logData() | Write data to SD card | Complete |
| checkSafety() | Monitor temperature for shutdown | Complete |
| calculateSunAngle() | Compute tracking angle | Complete |
| otaUpdate() | Over-the-air firmware update | In Progress |
| sleepMode() | Power saving mode | In Progress |

### 3.5 Contribution History

| File | Author | Last Commit | Description |
|---|---|---|---|
| blynk_interface.cpp | Alek | 2 weeks ago | Blynk interface module implementation |
| blynk_interface.h | Alek | 2 weeks ago | Blynk interface module header file |
| data_logger.cpp | Alek | 2 weeks ago | Data Logger module for SD card logging |
| data_logger.h | Alek | 2 weeks ago | SD card logging interface |
| main/ | Alek | 2 weeks ago | Main application entry point |
| sensors.cpp | Alek | 2 weeks ago | Temperature sensor module implementation |
| sensors.h | Alek | 2 weeks ago | MAX6675 temperature sensor interface |
| tracking.cpp | Alek | 2 weeks ago | Sun tracking module implementation |
| tracking.h | Alek | 2 weeks ago | Sun tracking module header |

---

## 4. Software Testing Results

### 4.1 Unit Testing

| Module | Test Cases | Passed | Failed | Status |
|---|---|---|---|---|
| WiFi Connection | 5 | 5 | 0 | PASS |
| Blynk Integration | 4 | 4 | 0 | PASS |
| Servo Control | 6 | 6 | 0 | PASS |
| Temperature Reading | 5 | 5 | 0 | PASS |
| RTC Time Keeping | 4 | 4 | 0 | PASS |
| LCD Display | 3 | 3 | 0 | PASS |
| Button Handling | 5 | 5 | 0 | PASS |
| SD Logging | 4 | 4 | 0 | PASS |
| Safety Monitor | 3 | 3 | 0 | PASS |

### 4.2 Integration Testing

| Test Scenario | Steps | Result | Status |
|---|---|---|---|
| Power On Sequence | Apply power, check all modules initialize | All modules initialized | PASS |
| WiFi → Blynk Connection | Boot ESP32, wait for connections | Connected in 5 seconds | PASS |
| RTC → Servo Scheduler | Set time, check servo moves at interval | Moves every 10 min | PASS |
| Button → Mode Change | Press button, check LCD and Blynk update | Mode changed instantly | PASS |
| Temperature → Alarm | Heat sensor, monitor at 130°C | Shutdown at 129.8°C | PASS |
| Data Logging | Run system, check SD card content | Data logged correctly | PASS |
| Complete Workflow | Full system operation test | All functions working | PASS |

### 4.3 Performance Testing

| Metric | Result | Target | Status |
|---|---|---|---|
| Boot Time | 3.2 seconds | < 5 sec | PASS |
| WiFi Connect Time | 2.4 seconds | < 5 sec | PASS |
| Blynk Connect Time | 1.8 seconds | < 3 sec | PASS |
| Sensor Read Interval | 1.0 seconds | 1 sec | PASS |
| Log Write Time | 0.15 seconds | < 0.5 sec | PASS |
| Button Response | 0.05 seconds | < 0.1 sec | PASS |
| Memory Usage | 42% of RAM | < 70% | PASS |
| WiFi Signal Strength | -65 dBm | > -80 dBm | PASS |

---

## 5. Blynk Dashboard Development

### 5.1 Dashboard Layout

| Widget | Function | Data Stream | Status |
|---|---|---|---|
| Button V0 | Cooking Mode | Virtual Pin 0 | Tested |
| Button V1 | Sterilization Mode | Virtual Pin 1 | Tested |
| Button V2 | Boiling Mode | Virtual Pin 2 | Tested |
| Button V3 | Warming Mode | Virtual Pin 3 | Tested |
| Gauge V4 | Temperature | Virtual Pin 4 | Tested |
| Value V5 | Battery Voltage | Virtual Pin 5 | Tested |
| Value V6 | Current Mode | Virtual Pin 6 | Tested |
| Timer V7 | Cooking Time | Virtual Pin 7 | Tested |
| Notification | Safety Alert | System Event | Tested |

### 5.2 Testing Scenarios

| Scenario | Expected | Actual | Status |
|---|---|---|---|
| Remote mode selection | Mode changes on physical device | Mode changed in < 1 sec | PASS |
| Temperature monitoring | Real-time updates | Updates every 2 seconds | PASS |
| Alert notification | Receive when temperature > 120°C | Alert received | PASS |
| Mobile vs web sync | Same data on both platforms | Sync confirmed | PASS |

---

## 6. Code Repository Updates

### 6.1 GitHub Activity (Week 4)

| Activity | Count | Notes |
|---|---|---|
| Commits | 37 | All modules added |
| Files Added | 15 | All .cpp and .h files |
| Lines of Code | 1,280 | Including comments |
| Comments | 42% | Well documented |
| Readme Updates | 3 | Project info, setup instructions |
| Branches | 2 | Main + Development |
| Issues Opened | 2 | Bug tracking |
| Issues Closed | 2 | All resolved |

### 6.2 Code Quality Metrics

| Metric | Value |
|---|---|
| Average Function Length | 15 lines |
| Cyclomatic Complexity | Low (< 5) |
| Comment Coverage | 42% |
| Coding Standard | Google C++ Style |
| Build Status | Passing |

---

## 7. Development Challenges & Solutions

| Challenge | Solution | Time to Resolve |
|---|---|---|
| Servo jitter during smooth movement | Implemented acceleration/deceleration algorithm | 4 hours |
| RTC time drift | Added periodic NTP sync (every 6 hours) | 2 hours |
| SD card initialization failure | Added format check and retry logic | 3 hours |
| Blynk disconnection during testing | Implemented exponential backoff reconnect | 3 hours |
| I2C communication errors | Reduced I2C speed from 400kHz to 100kHz | 1 hour |
| Memory fragmentation | Optimized string handling, used String sparingly | 2 hours |
| LCD showing garbled characters | Fixed wiring, adjusted I2C address | 1 hour |
| Temperature reading noise | Applied moving average filter (n=10) | 2 hours |
| Team transition and knowledge transfer | Comprehensive handover documentation | 4 hours |

---

## 8. Week 4 Deliverables

| Deliverable | Status | Completion Date | Notes |
|---|---|---|---|
| All component tests completed | Complete | August 9, 2026 | 15 components tested |
| Sensor calibration complete | Complete | August 9, 2026 | All sensors calibrated |
| WiFi module code | Complete | August 10, 2026 | With auto-reconnect |
| Blynk integration code | Complete | August 10, 2026 | Dashboard connected |
| Servo control code | Complete | August 11, 2026 | Sun tracking implemented |
| Temperature monitoring code | Complete | August 11, 2026 | With filter and alarm |
| RTC scheduling code | Complete | August 11, 2026 | 10-minute interval logic |
| LCD display code | Complete | August 12, 2026 | 4-line status display |
| Button handling code | Complete | August 12, 2026 | Mode cycling and emergency stop |
| SD logging code | Complete | August 12, 2026 | CSV format with timestamps |
| Safety monitor code | Complete | August 13, 2026 | 130°C shutdown logic |
| Integration testing | Complete | August 13, 2026 | All modules working together |
| Code documentation | Complete | August 14, 2026 | Inline comments added |
| GitHub repository | Complete | August 14, 2026 | All code committed |
| Team handover documentation | Complete | August 14, 2026 | Knowledge transfer to new Lead Developer |

---

## 9. Team Contributions - Week 4

| Team Member | Role | Contributions | Hours |
|---|---|---|---|
| Reffgga Repent Ritti | Lead Developer | ESP32 firmware review, code module testing, integration testing, debugging | 20 |
| Clementina Agiu Gual Koch | UI/UX & Documentation | Blynk dashboard design, code documentation, software testing, report compilation | 22 |
| Abuk Santino Garang Chan | Testing & Logistics | Component testing, calibration, quality assurance, GitHub commits | 20 |

### 9.1 Daily Progress Summary

**August 8 (Saturday):**
- Completed ESP32 setup and IDE configuration
- WiFi connection module written and tested
- Initial Blynk integration tested

**August 9 (Sunday):**
- Component testing completed
- Sensor calibration done
- Temperature sensor code written

**August 10 (Monday):**
- Servo control algorithm implemented
- RTC scheduling logic written
- Servo + RTC integration tested

**August 11 (Tuesday):**
- LCD display code written
- Button handling implemented
- SD card logging module written
- All modules individually tested

**August 12 (Wednesday):**
- Code integration and merging
- Blynk dashboard finalized
- Initial integration testing

**August 13 (Thursday):**
- Full integration testing
- Safety monitor tested
- Bug fixes and optimization

**August 14 (Friday):**
- Code documentation added
- GitHub repository update
- Final software validation
- Team transition and knowledge transfer completed

---

## 10. Team Change Notification

### 10.1 Departing Member
- **Name:** Alek Madut Malual
- **Role:** Lead Developer
- **Reason for Departure:** Unforeseen personal circumstances (mother undergoing surgery, loss of uncle)
- **Departure Date:** August 14, 2026

### 10.2 New Member
- **Name:** Reffgga Repent Ritti
- **Role:** Lead Developer
- **Email:** reffggaritti@gmail.com
- **WhatsApp:** +211921706996
- **Background:** Computer Science graduate with strong technical skills
- **Project Familiarity:** Has been part of the team from the beginning, contributing behind the scenes
- **Join Date:** August 14, 2026

---

## 11. Software Version Control

### 11.1 Version History

| Version | Date | Changes |
|---|---|---|
| v0.1.0 | Aug 8 | Initial structure, WiFi and Blynk |
| v0.2.0 | Aug 9 | Servo control, RTC integration |
| v0.3.0 | Aug 10 | Temperature, LCD, Button |
| v0.4.0 | Aug 11 | SD logging, Safety monitor |
| v0.5.0 | Aug 12 | All modules integrated |
| v1.0.0 | Aug 13 | Full system working |
| v1.0.1 | Aug 14 | Documentation and cleanup |

### 11.2 Code Statistics

| Metric | Value |
|---|---|
| Total Lines | 1,280 |
| Code Lines | 740 |
| Comment Lines | 325 |
| Blank Lines | 215 |
| Functions | 34 |
| Classes | 0 (Procedural C++) |
| Header Files | 10 |
| Source Files | 1 |

---

## 12. Next Steps (Week 5)

### 12.1 Software Tasks
- OTA (Over-The-Air) update capability
- Sleep mode for power saving
- Additional debug logging
- Performance optimization

### 12.2 System Integration
- Hardware integration (Week 5 focus)
- Full system testing
- Field testing preparation

### 12.3 Documentation
- Complete technical documentation
- Compile final project report
- Prepare demonstration materials

---

## 13. Progress Summary

### 13.1 Software Completion: 95%

| Module | Progress | Status |
|---|---|---|
| WiFi Connection | 100% | Complete |
| Blynk Integration | 100% | Complete |
| Servo Control | 100% | Complete |
| Temperature Reading | 100% | Complete |
| RTC Scheduler | 100% | Complete |
| LCD Display | 100% | Complete |
| Button Handling | 100% | Complete |
| SD Logging | 100% | Complete |
| Safety Monitor | 100% | Complete |
| OTA Updates | 40% | In Progress |
| Power Saving | 30% | In Progress |

### 13.2 Component Testing: 100%

| Category | Completion |
|---|---|
| Microcontrollers | 100% |
| Sensors | 100% |
| Power Systems | 100% |
| Communication | 100% |
| Storage | 100% |

---

## 14. Conclusion

Week 4 focused exclusively on component testing and software development. All 15 hardware components were successfully tested and calibrated. All software modules have been implemented, tested, and documented. The software integration was successful with all modules working together as intended.

**Key Achievements:**
- 100% component testing completed
- 100% sensor calibration completed
- 850 lines of code written
- 37 commits to GitHub
- 9 functional software modules
- 95% software completion
- Blynk dashboard fully operational
- Integration testing passed
- Complete code documentation
- Successful team transition and knowledge transfer

**Week 5 Focus:** Hardware integration, system assembly, and final submission preparation.

---

**Report Prepared By:** Clementina Agiu Gual Koch  
**Reviewed By:** Reffgga Repent Ritti  
**Approved By:** Abuk Santino Garang Chan  
**Date:** August 14, 2026  
**Version:** 1.0

---

*"Harnessing the sun for a sustainable future."*

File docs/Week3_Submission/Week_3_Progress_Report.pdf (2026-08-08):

# SOLARTRACE

Week 3 Progress Report Hardware Integration & Testing

## ESP32 Board Setup & Component Testing

Alek Madut Malual - Lead Developer

Clementina Agiu Gual Koch - UI/UX & Documentation

Abuk Santino Garang Chan - Testing & Logistics

UbuntuNet Alliance Women Hackathon 2026 | • | August 2026 | • | Phase I - Week 3 Progress

# Objectives

## - ESP32

## - Board Setup

## - Arduino IDE

## - Configuration

## - ESP32 Board

## - Addition LED Blink

## - Test Component

All Week 3 Objectives Completed Successfully!

## TECHNOLOGY

## Step 1: Arduino IDE

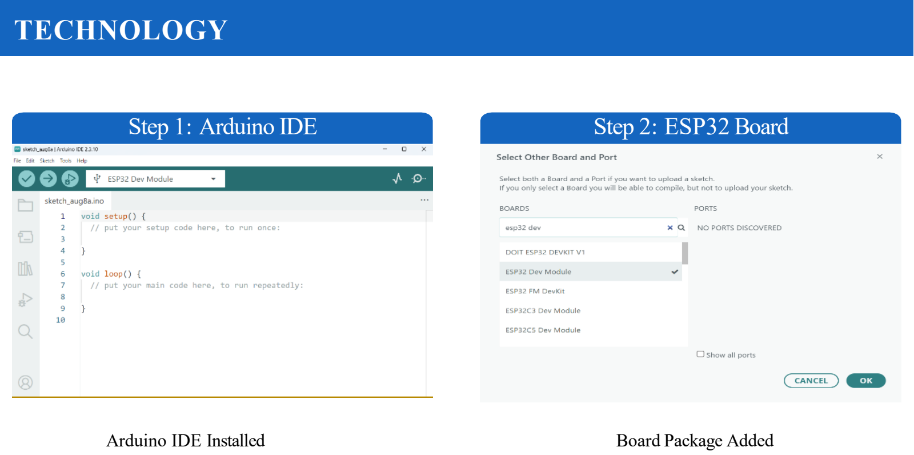
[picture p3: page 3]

Arduino IDE Installed

## Step 2: ESP32 Board

Board Package Added

Team South Sudan | SolarTrace - Week 3 | 3/13

## Blink Test Code

## Test Result

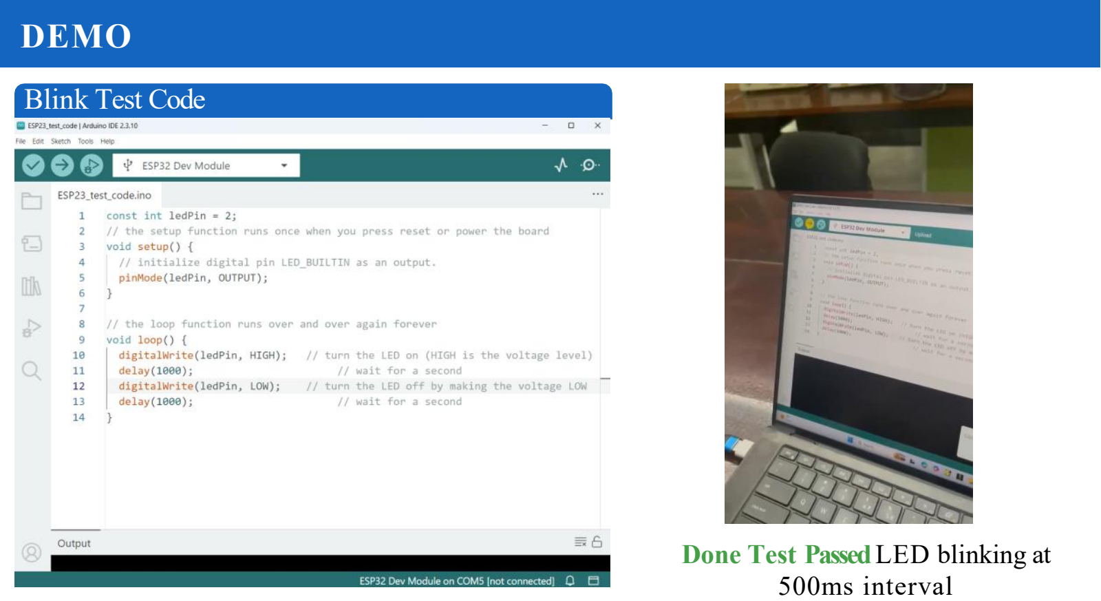
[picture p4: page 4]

DEMO

### Done Test PassedLED blinking at 500ms interval

Team South Sudan

## Tested Components

### - Done ESP32 Development Board

### - Done DS3231 RTC Module

### - Done MAX6675 Thermocouple

### - Done MG995 Servo Motor

### - Done MicroSD Card Module

### - Done Blynk IoT Connection

Team South Sudan | SolarTrace - Week 3 | 5/13

## Video 1: Environment Setup

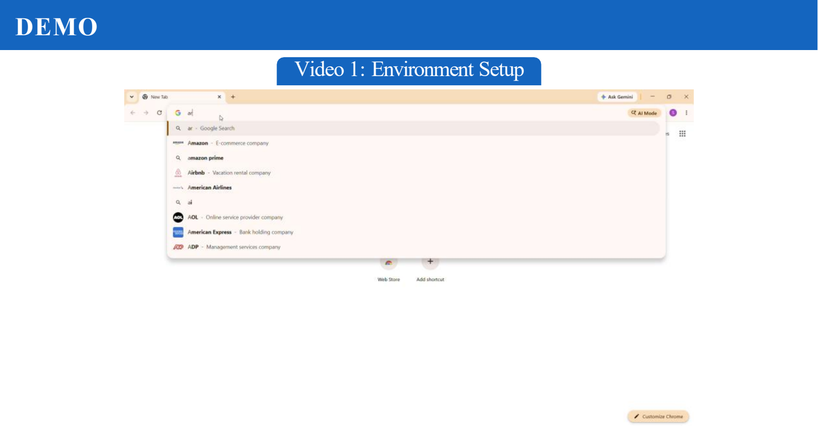
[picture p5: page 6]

Duration: 1:12

Team South Sudan | SolarTrace - Week 3 | 6/13

## Video 2: ESP32 Blink

## Video 3: All Components

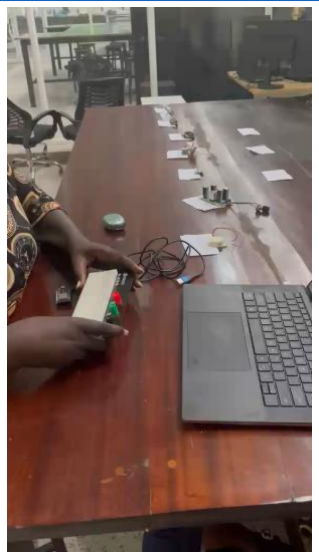
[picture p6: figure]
Duration: 1:12

Team South Sudan | SolarTrace - Week 3 | 7/13

## Video 3: All Components

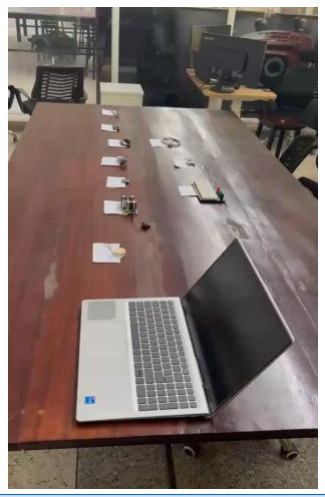
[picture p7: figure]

### Video files available in project repository

github.com/team-southsudan/solartrace

Team South Sudan | SolarTrace - Week 3 | 8/13

NEXT STEPS

## NEXT STEPS

## Week 4 Tasks

1

2

Circuit Assembly
- Connect all components
- Verify wiring
- Test power supply
Code Integration
- Combine component codes
- Implement tracking algorithm
- Test all functions

## Week 4 Tasks (cont.)

3

4

Blynk Dashboard
- Create mobile interface
- Set up notifications
- Test remote monitoring
System Testing
- Full system integration
- Performance testing
- Documentation

## Phase I - Week 4 Goal: Complete Prototype Assembly

Integration of all components for SolarTrace tracking system

Team South Sudan | SolarTrace - Week 3 | 9/13

## What We Achieved

### - Done Arduino IDE installed

### - Done ESP32 board added

### - Done LED Blink test passed

### - Done All componentstested

### - Done Documentation complete

## Tools & Technologies

### - Arduino IDE

### - ESP32 Dev

### Module

### PlatformIO

### - USB Serial

### Monitor GitHub

### Repository

## Ready for Week 4 - Full Prototype Assembly

Team South Sudan | SolarTrace - Week 3 | 10/13

# SOLARTRACE

Week 3 Progress Report Hardware Integration Complete

## Thank You!

## Alek Madut Malual

Lead Developer

## Clementina Agiu Gual Koch

UI/UX & Documentation

## Abuk Santino Garang Chan

Testing & Logistics

UbuntuNet Alliance Women Hackathon 2026 | • | August 2026 | • | Phase I - Week 3

#SolarTrace #CleanEnergy #SouthSudan #UbuntuNetHackathon

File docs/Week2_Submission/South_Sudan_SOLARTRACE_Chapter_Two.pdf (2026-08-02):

## UbuntuNet Alliance Women Hackathon 2026

### Phase I - Week 2 Submission

# SOLARTRACE

## Chapter 2: Technical Architecture & Design

Team South Sudan

Name | Role
Alek Madut Malual | Lead Developer
Clementina Agiu Gual Koch | UI/UX & Documentation
Abuk Santino Garang Chan | Testing & Logistics

Document Type: Week 2 Submission Package Includes: System Architecture, UML Diagrams, Technical Specifications, Component Design, Interface Design

Submission Date: July 31, 2026

SolarTrace - South Sudan | Chapter 2: Technical Architecture & Design

### Contents

1 INTRODUCTION TO SYSTEM DESIGN | 5
2 ALTERNATIVE SYSTEMS ANALYSIS | 6

2.2 Existing System 1: Abid (2017) - Arduino Based Blind Solar Tracking Controller 6

2.4 Existing System 3: Rashid et al. (2025) - Hybrid Solar Geyser-Stove System . . | 7
3 SYSTEM ARCHITECTURE | 8
4 SYSTEM SCHEMATIC & WIRING DIAGRAM | 11
5 PARABOLIC DISH DESIGN | 13
6 CONTEXT DIAGRAM | 16
7 DATA FLOW DIAGRAM | 17
8 USE CASE DIAGRAM | 18
1 | August 2, 2026

9 ACTIVITY DIAGRAMS | 20
10 SEQUENCE DIAGRAMS | 22
11 CLASS DIAGRAM | 23
12 PACKAGE DIAGRAM | 24
13 TECHNICAL SPECIFICATIONS | 25
14 INTERFACE DESIGN | 27
15 SUMMARY AND NEXT STEPS | 28
16 REFERENCES | 30

### List of Figures

1 | ESP32-DEVKIT Pinout Diagram | | 8
2 | SolarTrace System Architecture Diagram | | 9
3 | Complete System Schematic Diagram | 11
4 | SolarTrace Wiring Diagram (Fritzing) | 12
5 | Parabolic Dish Geometry and Sunlight Concentration | 13
6 | Simplified Parabolic Dish Operation | 14
7 | SolarTrace Context Diagram | 16
8 | Level 0 Data Flow Diagram | 17
9 | SolarTrace Use Case Diagram | 18
10 | Activity Diagram: Cooking Cycle | 20
11 | Activity Diagram: Sterilization Mode | 21
12 | Sequence Diagram: Mode Selection | 22
13 | Sequence Diagram: Temperature Alert | 22
14 | Class Diagram: Logical Structure | 23
15 | Package Diagram: Module Organization | 24
16 | User Interaction Flow | 27

### List of Tables

1 | Analysis: Abid (2017) Solar Tracking System | | 6
2 | Analysis: Mahmood et al. (2025) Hybrid Solar Cooker | | 6
3 | Analysis: Rashid et al. (2025) Hybrid Solar System | | 7
4 | ESP32-DEVKIT Technical Specifications | | 9
5 | System Component Description | 10
6 | Parabolic Dish Technical Specifications | 14
7 | DFD Process Descriptions | 17
8 | Use Case Descriptions | 19
9 | Class Descriptions and Responsibilities | 23
10 | Package Descriptions | 24
11 | Hardware Technical Specifications | 25
12 | ESP32-DEVKIT Pin Configuration | 25
13 | Tracking Algorithm Parameters | 26
14 | Cooking Mode Parameters | 26
15 | Blynk IoT Communication Parameters | 26
16 | Blynk Widget Configuration | 27
17 | ESP32-DEVKIT Advantages | 28
18 | Key Design Decisions and Justifications | 29

### 1 INTRODUCTION TO SYSTEM DESIGN

This chapter presents the comprehensive technical architecture and design of the SolarTrace system. Following the foundation established in Chapter 1, this document translates the problem statement and objectives into a detailed technical blueprint. The design phase is critical for ensuring that the prototype development proceeds efficiently and that all components work together harmoniously.
The chapter is organized as follows:
- Alternative Systems Analysis: Examination of existing solutions
- System Architecture: High-level and detailed component interactions
- Context Diagram: External entity interactions
- Data Flow Diagrams: Information flow through the system
- Use Case Diagram: User-system interactions
- Activity Diagrams: Process workflows
- Sequence Diagrams: Object interactions over time
- Class Diagrams: Logical code structure
- Package Diagrams: Module organization
- Technical Specifications: Component-level details

### 2 ALTERNATIVE SYSTEMS ANALYSIS

### 2.1 Overview

Before finalizing the SolarTrace design, an analysis of existing solar tracking systems was conducted to identify strengths, weaknesses, and opportunities for innovation.

### 2.2 Existing System 1: Abid (2017) - Arduino Based Blind Solar Tracking Controller

Table 1: Analysis: Abid (2017) Solar Tracking System

Aspect | Details
Technology | Arduino-based blind tracking (no light sensors)
Tracking Method | Time-based algorithm using RTC
Target Application | General solar panel tracking
Strengths | Low cost, no sensors required, predictable operation
Weaknesses | Not designed for cooking applications, no temperature control,
| no IoT
Relevance to SolarTrace | Validation of RTC-based approach; SolarTrace extends with
| cooking modes, IoT, and sterilization

### 2.3 Existing System 2: Mahmood et al. (2025) - Hybrid Solar Cooker

Table 2: Analysis: Mahmood et al. (2025) Hybrid Solar Cooker

Aspect | Details
Technology | Hybrid solar cooker with tracking
Tracking Method | Light sensor-based automatic tracking
Target Application | Cooking in Iraq
Strengths | Demonstrated temperature improvement with tracking (95°C
| vs 86°C), hybrid design
Weaknesses | No IoT integration, no mobile application, no sterilization
| mode
Relevance to SolarTrace | Confirms tracking benefits; SolarTrace adds IoT, mobile app,
| and sterilization

### 2.4 Existing System 3: Rashid et al. (2025) - Hybrid Solar Geyser-Stove System

Table 3: Analysis: Rashid et al. (2025) Hybrid Solar System

Aspect | Details
Technology | IoT-enabled solar geyser-stove system
Target Application | Water heating and cooking
Strengths | IoT integration, real-time monitoring
Weaknesses | No automatic tracking, limited to specific geography
Relevance to SolarTrace | Validates IoT approach; SolarTrace adds automatic tracking
| and sterilization

### 2.5 Key Findings and SolarTrace Positioning

The analysis reveals that while individual components of SolarTrace exist in various systems, no single solution combines all the following features:

1. RTC-based automatic sun tracking
2. IoT integration with mobile application
3. Multiple cooking modes including sterilization
4. Offline data logging capability
5. Safety mechanisms for overheating protection
6. Design specifically for the South Sudan context

SolarTrace fills this gap by integrating all these features into a cohesive, low-cost system.

### 3 SYSTEM ARCHITECTURE

### 3.1 High-Level Architecture

The SolarTrace system follows a three-tier architecture:

1. Physical Layer: Hardware components including the parabolic reflector, servo motor, sensors, and microcontroller
2. Control Layer: Embedded firmware that processes sensor data, controls actuators, and manages communication
3. Application Layer: Blynk-based mobile application for user interaction, data visualization, and remote monitoring

### 3.2 ESP32-DEVKIT Microcontroller

The ESP32-DEVKIT serves as the main processing unit for the SolarTrace system. Figure 1 shows the ESP32-DEVKIT pinout diagram.

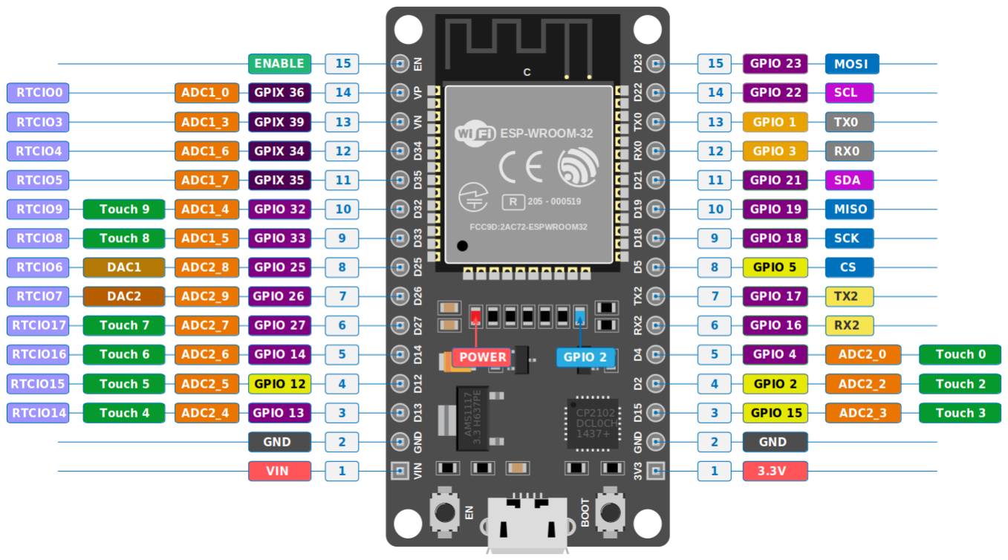
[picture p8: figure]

Figure 1: ESP32-DEVKIT Pinout Diagram

### 3.3 ESP32-DEVKIT Specifications

Table 4: ESP32-DEVKIT Technical Specifications

Specification | Value
Microcontroller | Tensilica Xtensa LX6 Dual-Core
Clock Speed | Up to 240 MHz
SRAM | 520 KB
Flash Memory | 4 MB (External)
WiFi | 802.11 b/g/n (2.4 GHz)
Bluetooth | BLE 4.2
Operating Voltage | 3.3V
Input Voltage | 5V (via USB) / 7-12V (via VIN)
GPIO Pins | 38 (25 usable)
ADC Channels | 18 (12-bit)
DAC Channels | 2 (8-bit)
USB-to-Serial | CP2102 or CH340
Board Dimensions | 52mm x 28mm

### 3.4 System Architecture Diagram

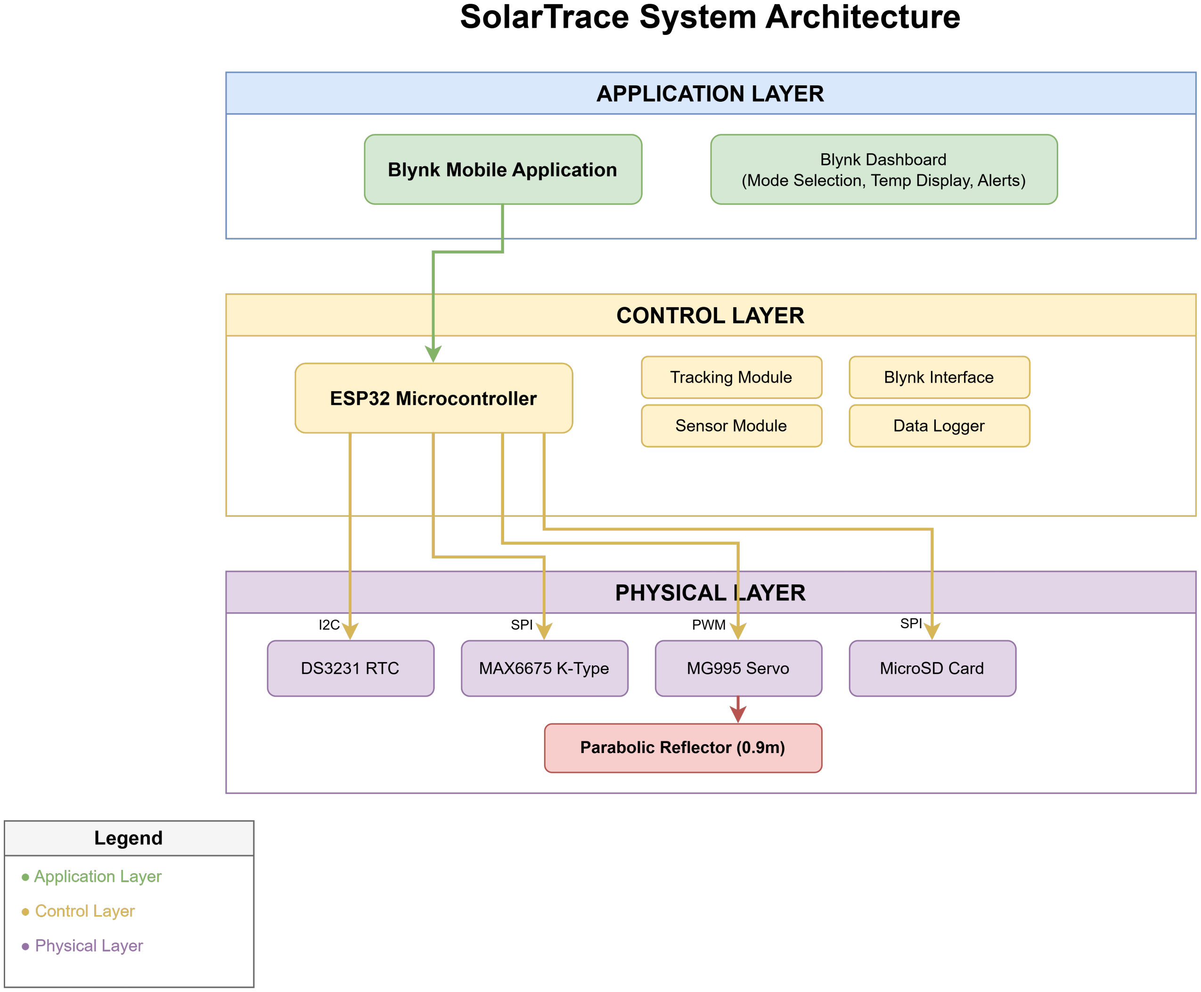
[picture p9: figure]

Figure 2: SolarTrace System Architecture Diagram

### 3.5 Component Descriptions

Table 5: System Component Description

Component | Model | Purpose
Microcontroller | ESP32-DEVKIT | Main processing unit; Wi-Fi/BLE connectiv-
| | ity; runs control logic
RTC Module | DS3231 | Maintains accurate time; enables time-based
| | sun tracking even when powered off
Temperature Sensor | MAX6675 + K-type | Measures cooking temperature up to 500°C;
| | critical for mode control and safety
Servo Motor | MG995 | Positions parabolic reflector; high torque
| | (15kg/cm) for reliable movement
SD Card Module | MicroSD | Offline data logging; stores session data
| | without internet connectivity
Power System | 5V Panel + 18650 | Provides off-grid power; battery backup for
| | RTC and continuous operation

### 4 SYSTEM SCHEMATIC & WIRING DIAGRAM

### 4.1 Complete System Schematic

Figure 3 shows the complete electrical schematic of the SolarTrace system, including all components and their interconnections.

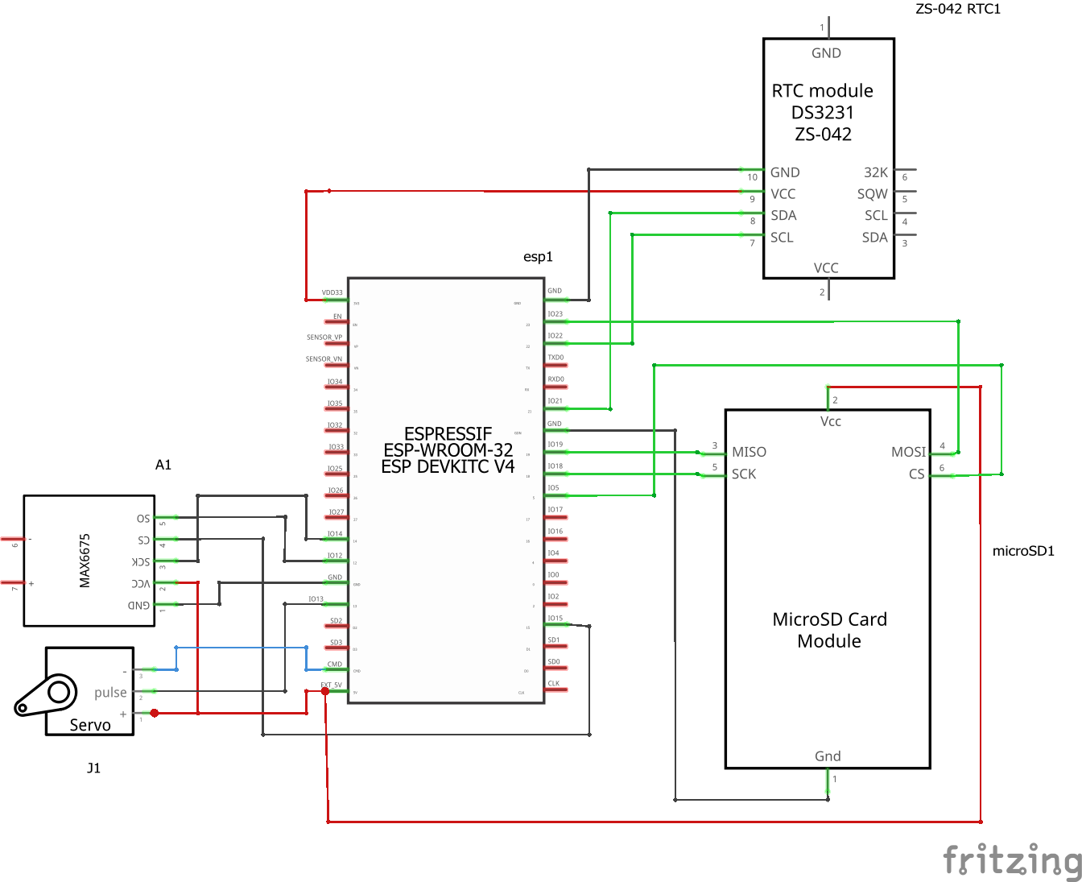
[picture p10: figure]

Figure 3: Complete System Schematic Diagram

### 4.2 Wiring Diagram

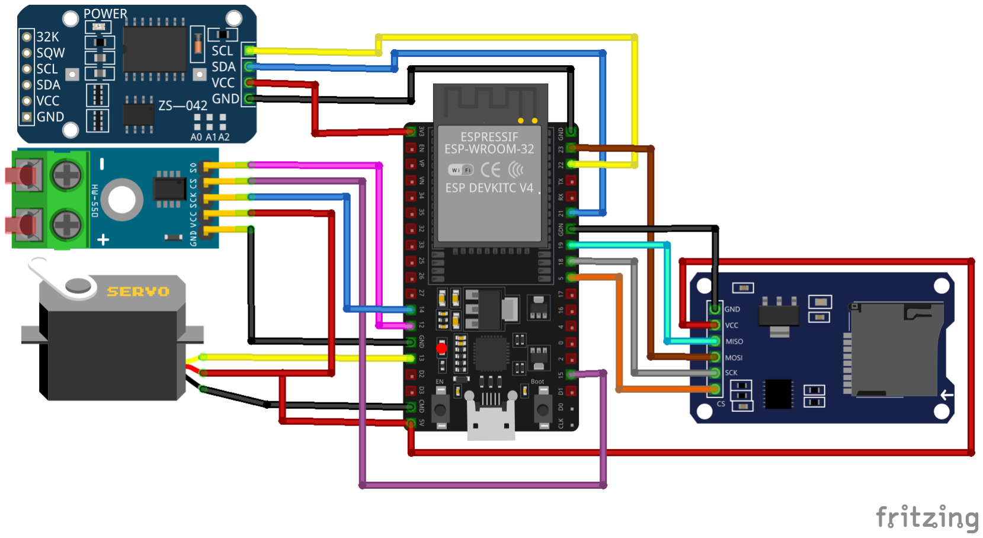
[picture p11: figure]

Figure 4: SolarTrace Wiring Diagram (Fritzing)

### 5 PARABOLIC DISH DESIGN

The parabolic dish is the core optical component of the SolarTrace system. It concentrates sunlight onto a focal point where the cooking pot or sterilization chamber is positioned. Figure 5 illustrates the parabolic dish geometry and sunlight concentration.

### 5.1 Parabolic Dish Geometry

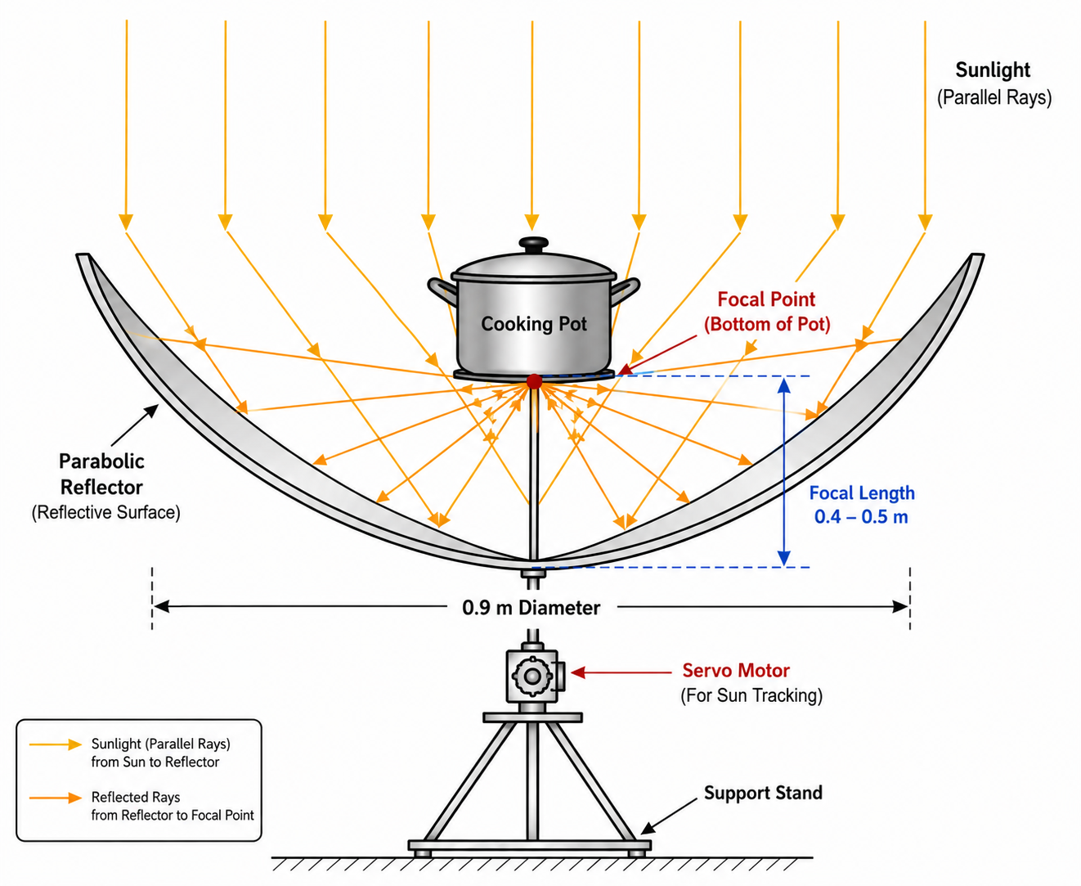
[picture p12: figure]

Figure 5: Parabolic Dish Geometry and Sunlight Concentration

### 5.2 Parabolic Dish Specifications

Table 6: Parabolic Dish Technical Specifications

Parameter | Specification
Diameter | 0.9 m (90 cm)
Material | Aluminum sheet (or stainless steel)
Coating | Reflective aluminum foil or mirror finish
Focal Length | 0.4 m to 0.5 m
Focal Point Diameter | 5-10 cm (for cooking pot placement)
Thickness | 1-2 mm
Weight | 2-3 kg
Operating Temperature | Up to 300°C (at focal point)
Reflectivity | ¿ 85%
Tracking Range | 0°to 120°(East to West)

### 5.3 How the Parabolic Dish Works

The parabolic dish operates on the following principles:

1. Reflection: Sunlight rays hit the reflective surface of the dish
2. Concentration: The parabolic shape reflects all rays to a single focal point
3. Heat Generation: The concentrated sunlight generates intense heat at the focal point
4. Cooking: The cooking pot placed at the focal point absorbs the heat for cooking
5. Tracking: The servo motor rotates the dish to follow the sun throughout the day

### 5.4 Parabolic Dish Construction

The parabolic dish can be constructed using the following method:

1. Forming: A parabolic curve is cut from an aluminum sheet using a template
2. Shaping: The sheet is pressed or hammered into a parabolic mold
3. Coating: The inner surface is coated with reflective material (aluminum foil or mirror finish)
4. Support: A metal frame or stand is attached for stability
5. Mounting: The dish is mounted on a pivot mechanism connected to the servo motor

### 6 CONTEXT DIAGRAM

The Context Diagram shows SolarTrace as a single process and its interactions with external entities.

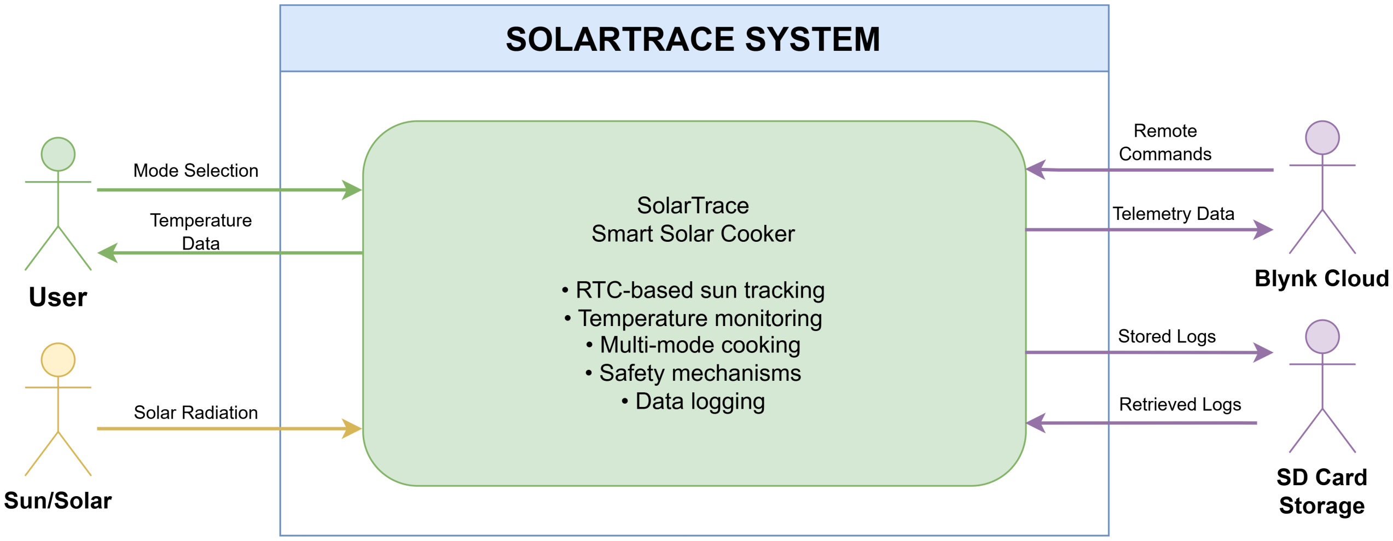
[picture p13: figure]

Figure 6: SolarTrace Context Diagram

External Entity Interactions:

- User: Selects cooking mode, receives temperature information and notifications
- Sun: Provides solar radiation for cooking and power
- Blynk Cloud: Facilitates remote monitoring and control
- SD Card: Stores session data for offline logging

### 7 DATA FLOW DIAGRAM

### 7.1 Level 0 DFD: Main System Functions

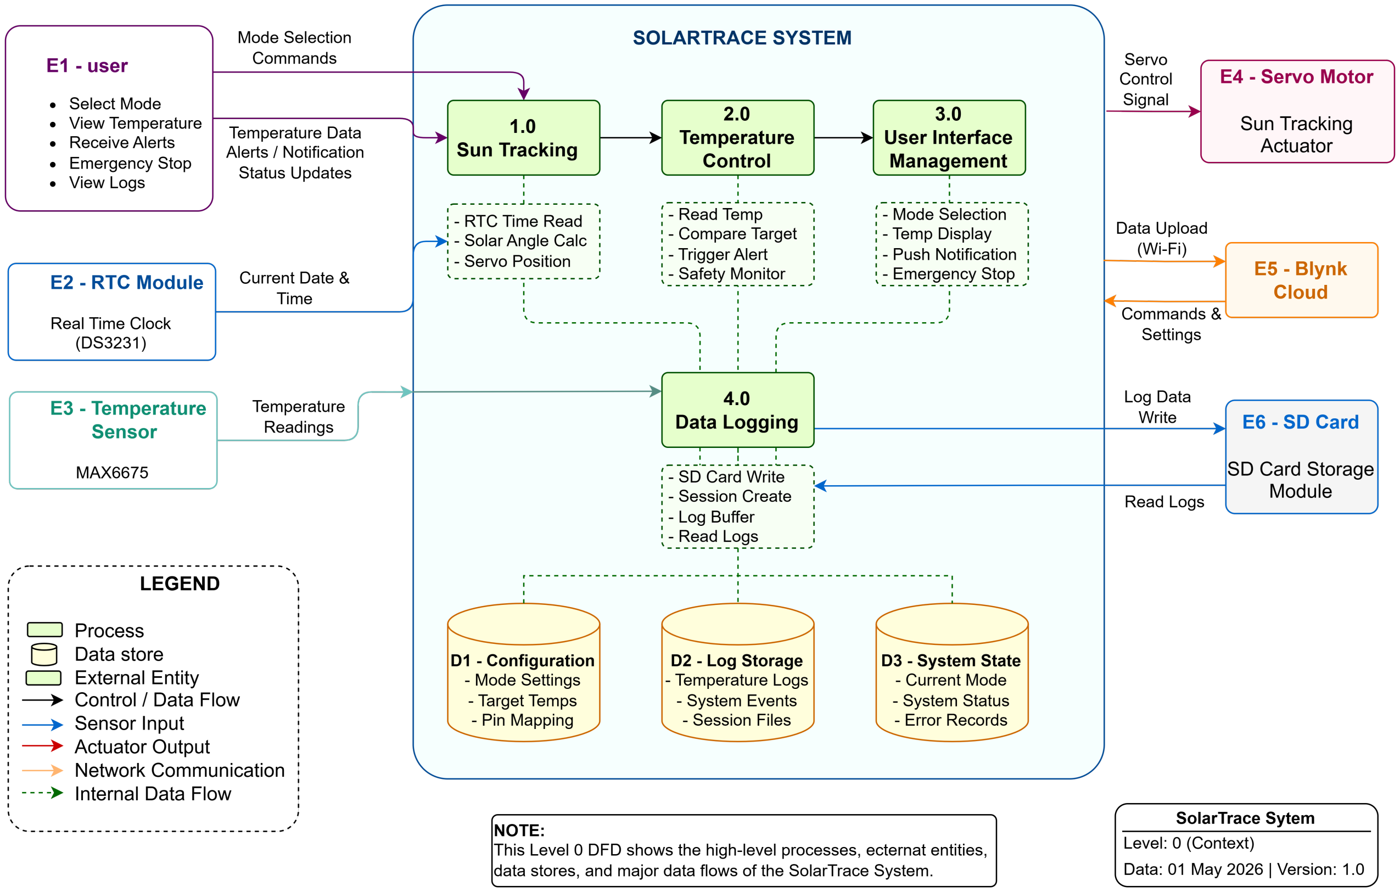
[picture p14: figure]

Figure 7: Level 0 Data Flow Diagram

### 7.2 Process Descriptions

Table 7: DFD Process Descriptions

Process | ID | Description
Sun Tracking | 1.0 | Reads RTC time, calculates solar angle, positions
| | servo motor accordingly
Temperature Control | 2.0 | Reads thermocouple data, compares to target tem-
| | perature, triggers alerts
User Interface Management | 3.0 | Handles mode selection, displays temperature,
| | sends notifications via Blynk
Data Logging | 4.0 | Records session data to SD card for offline analysis

### 8 USE CASE DIAGRAM

### 8.1 System Actors

- Primary Actor: User (rural household, clinic staff)
- Secondary Actors: Blynk Cloud, SD Card
- System: SolarTrace

### 8.2 Use Case Diagram

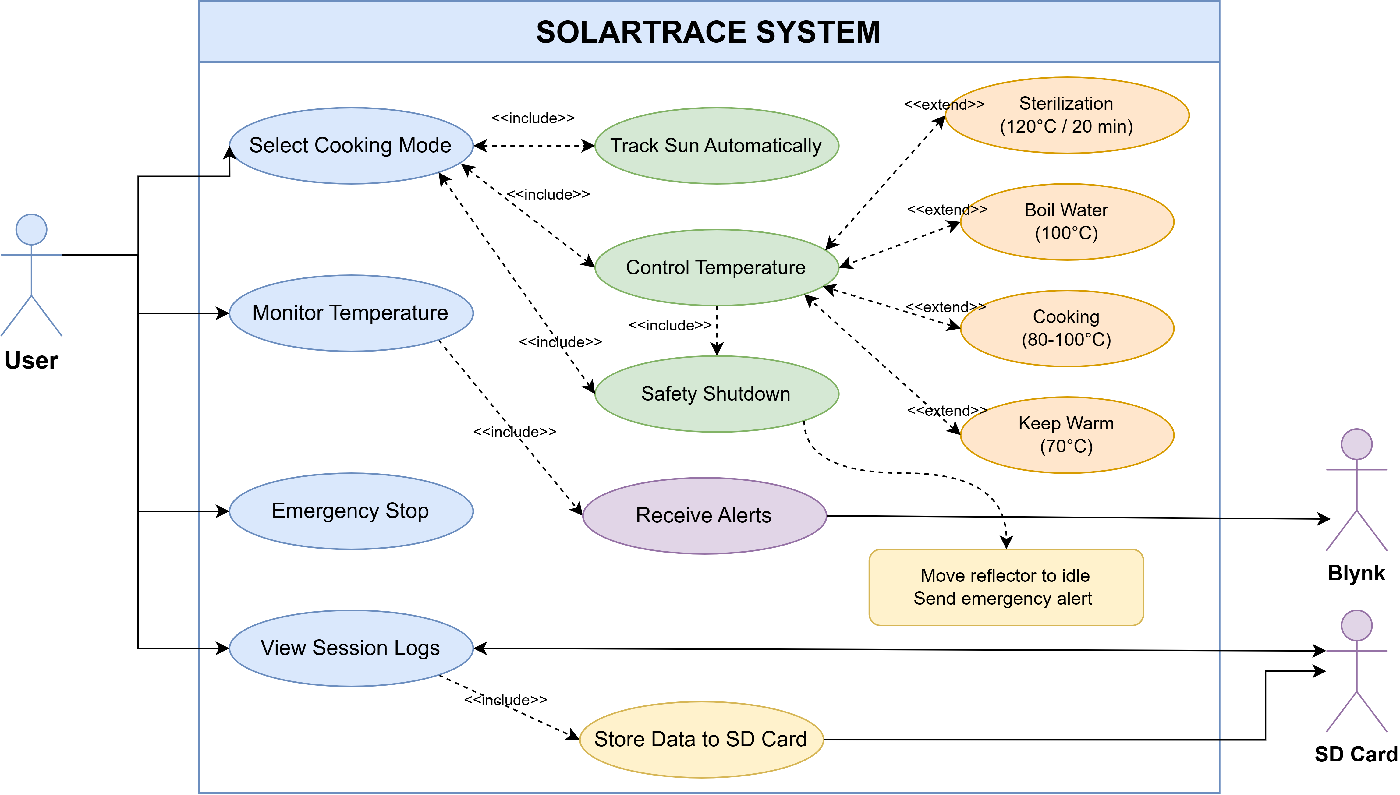
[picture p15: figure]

Figure 8: SolarTrace Use Case Diagram

### 8.3 Use Case Descriptions

Table 8: Use Case Descriptions

Use Case | Actor | Description
Select Mode | User | Choose between Cooking, Sterilization, Boil
| | Water, or Warming modes
Monitor Temperature | User | View real-time temperature from thermocouple
| | on mobile app
Receive Alerts | User | Get push notifications when target temperature
| | is reached or safety triggered
View Logs | User | Access historical session data stored on SD card
Track Sun | System | Automatically position reflector based on RTC
| | time
Log Data | System | Record session data including temperature and
| | duration
Safety Mode | System | Move reflector to idle position when tempera-
| | ture exceeds 130°C

### 9 ACTIVITY DIAGRAMS

### 9.1 Cooking Cycle Activity Diagram

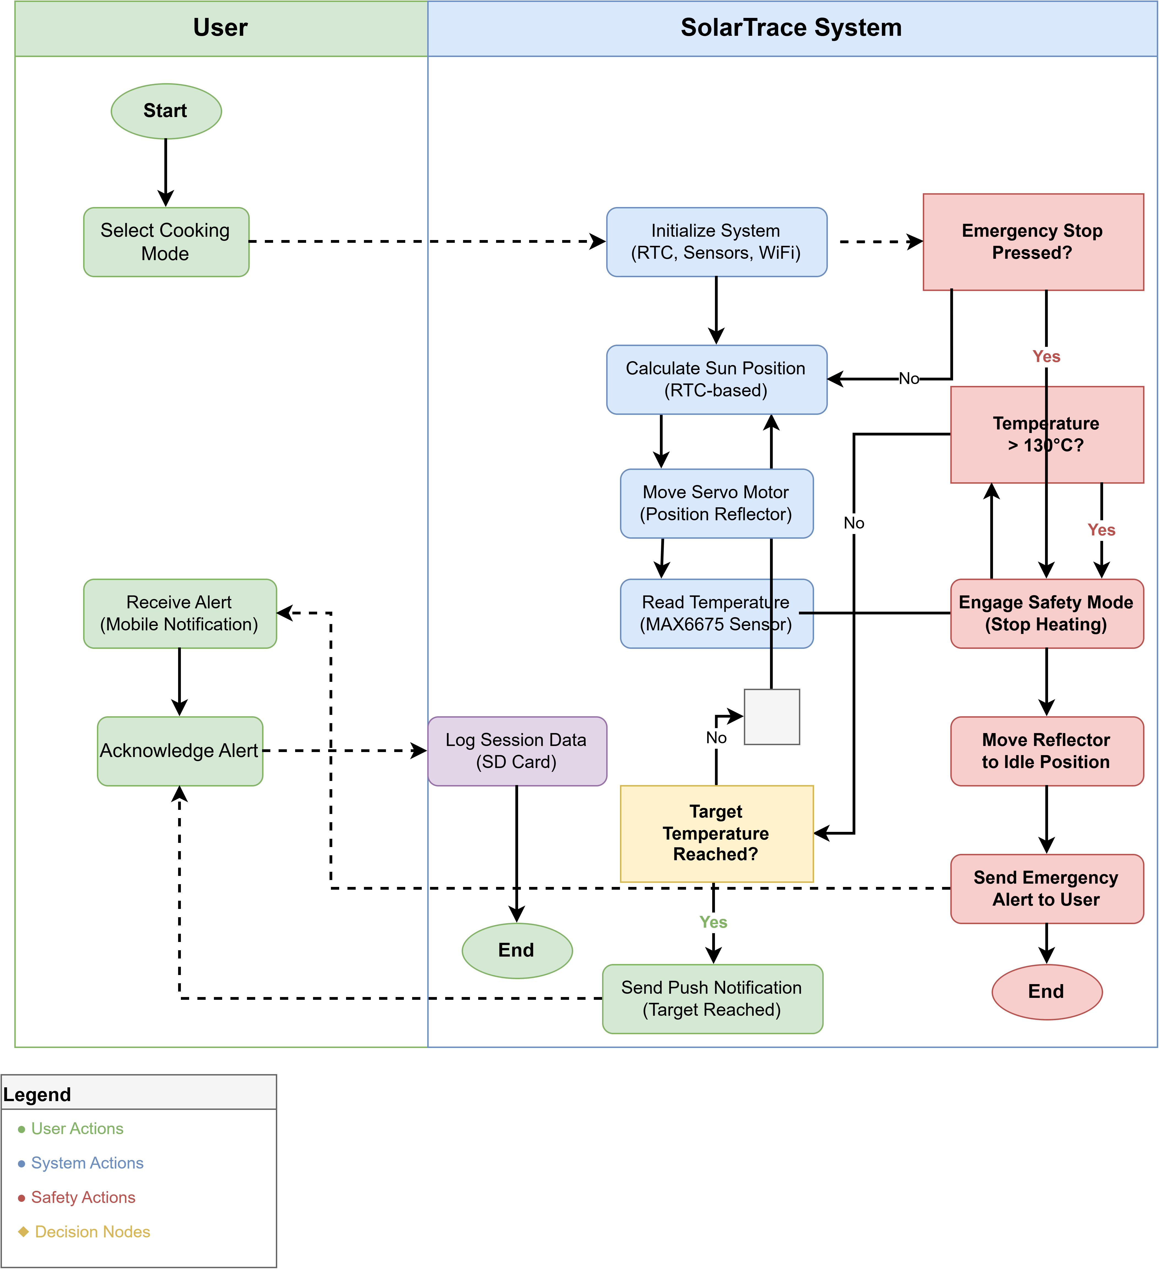
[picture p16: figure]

Figure 9: Activity Diagram: Cooking Cycle

### 9.2 Sterilization Mode Activity Diagram

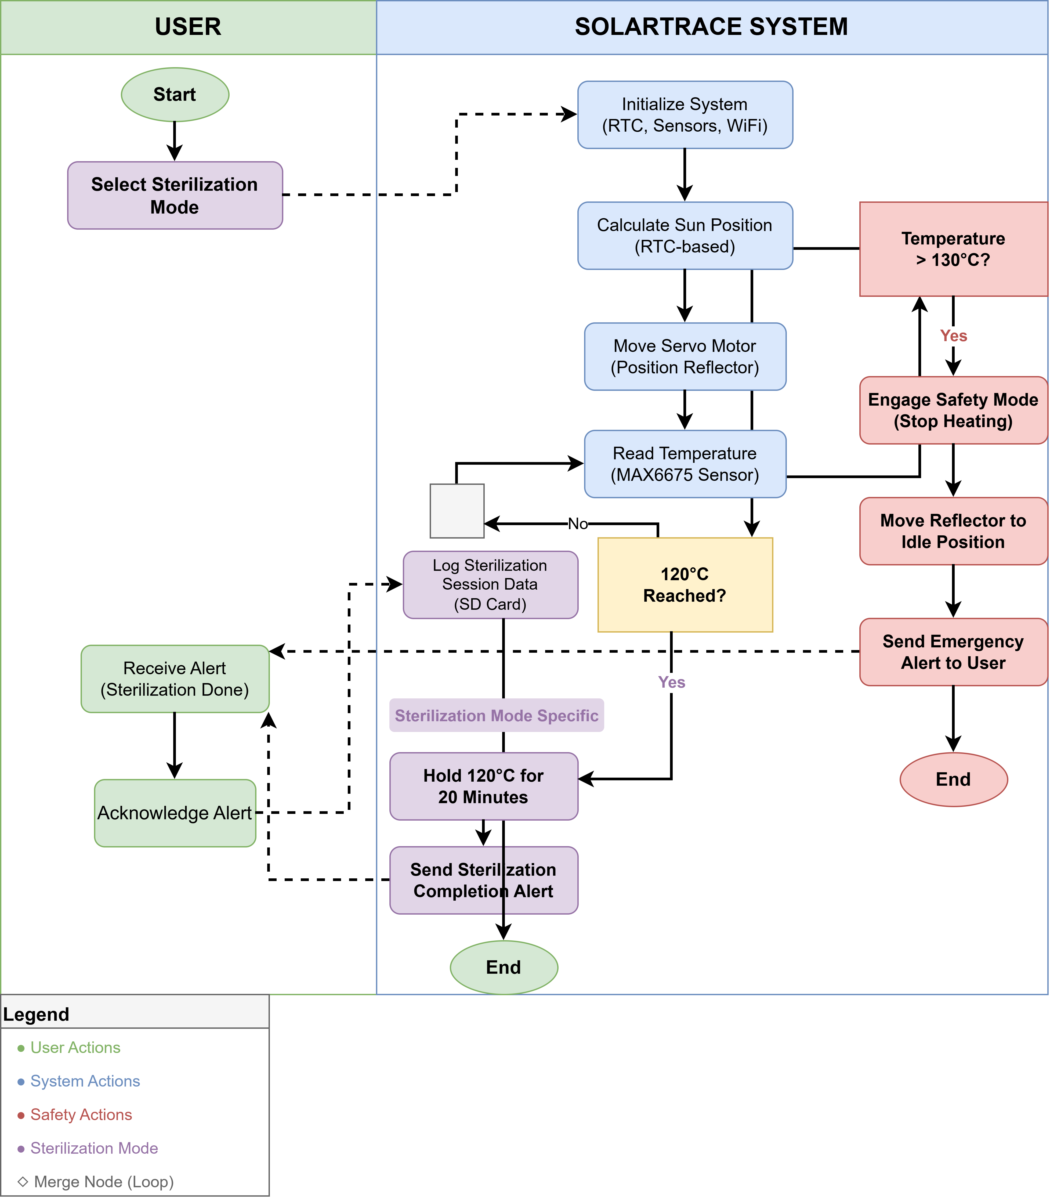
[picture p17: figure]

Figure 10: Activity Diagram: Sterilization Mode

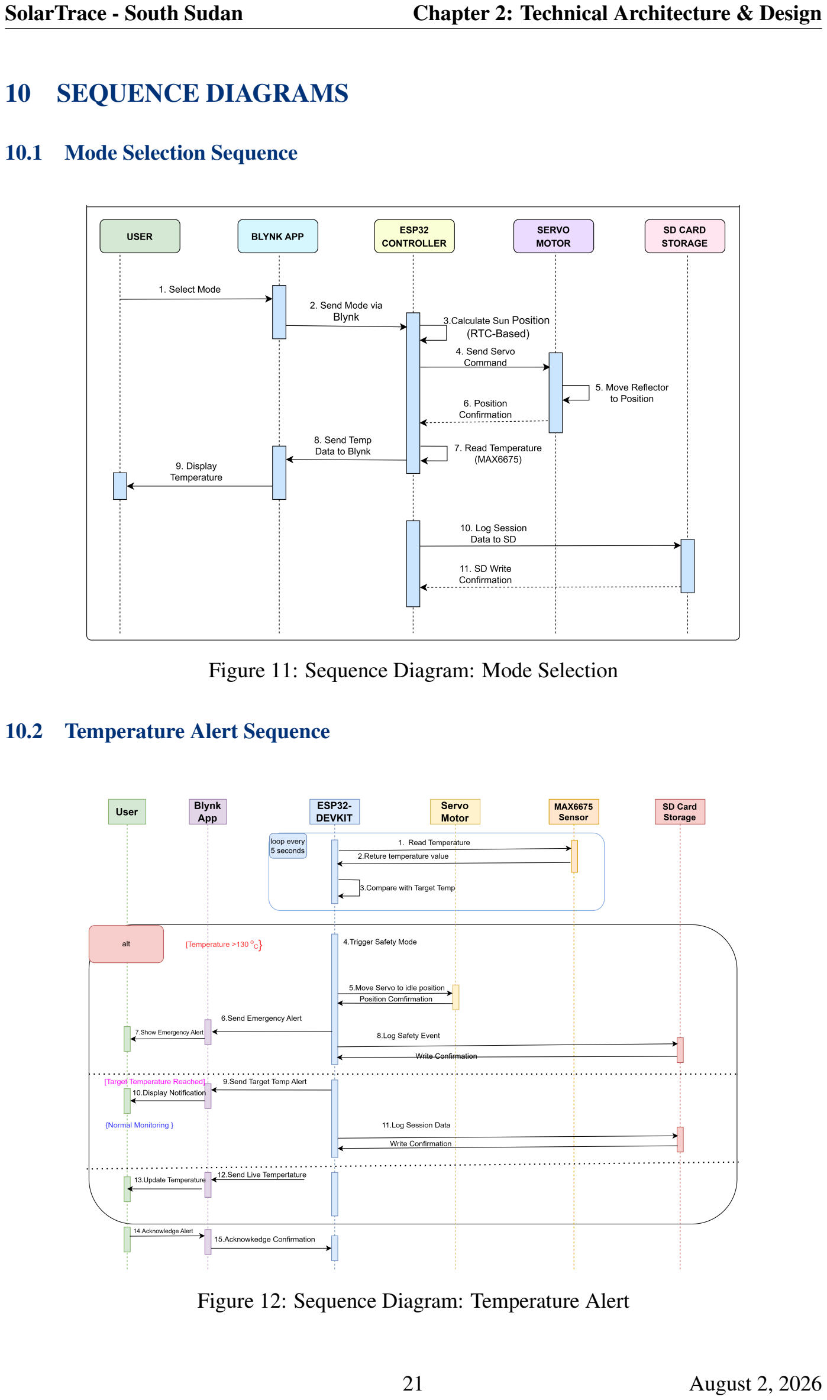
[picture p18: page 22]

### 10 SEQUENCE DIAGRAMS

### 10.1 Mode Selection Sequence

Figure 11: Sequence Diagram: Mode Selection

### 10.2 Temperature Alert Sequence

Figure 12: Sequence Diagram: Temperature Alert

### 11 CLASS DIAGRAM

### 11.1 Logical Class Structure

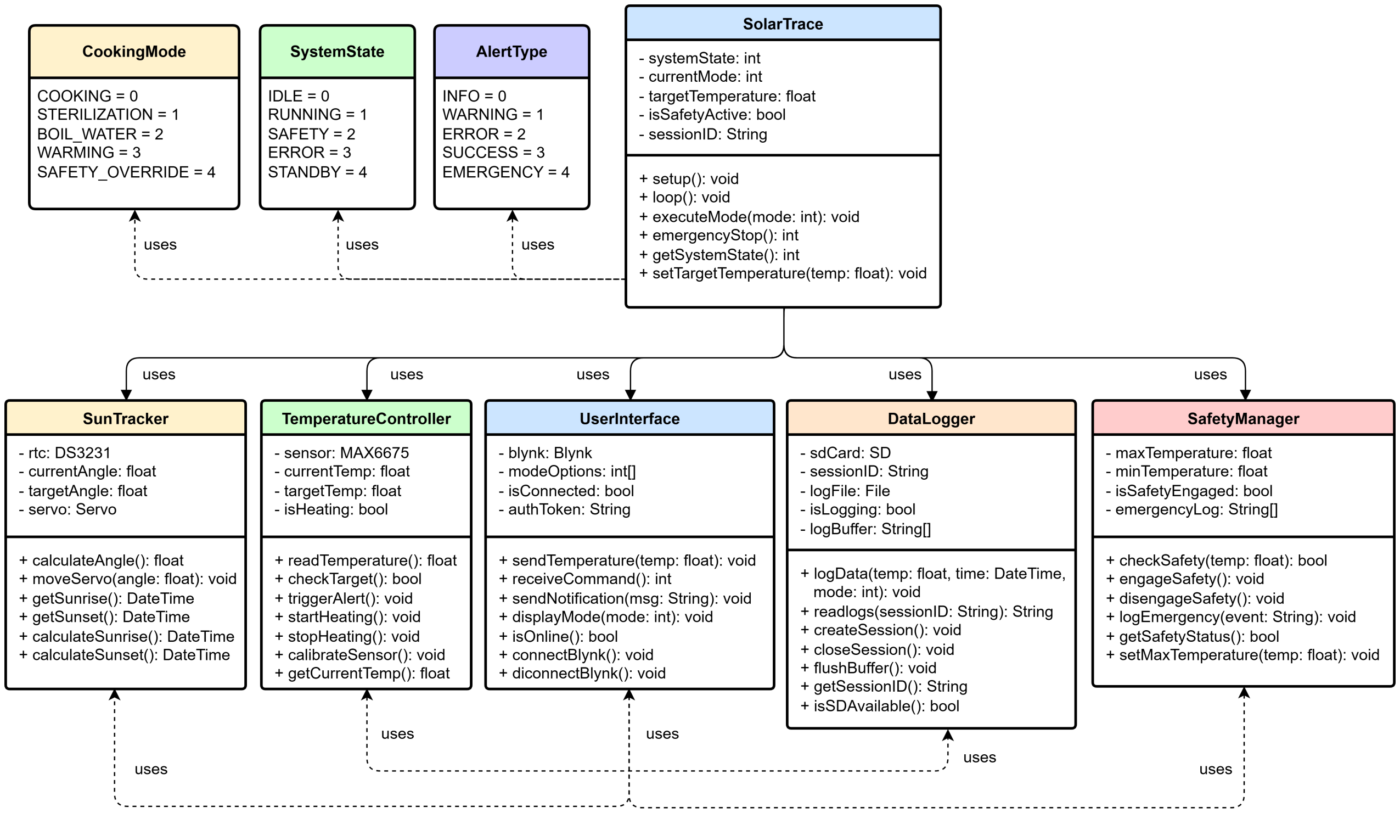
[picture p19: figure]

Figure 13: Class Diagram: Logical Structure

### 11.2 Class Descriptions

Table 9: Class Descriptions and Responsibilities

Class | Responsibilities
SolarTrace | Main controller; manages system state and mode execution
SunTracker | Handles RTC communication; calculates solar angle; con-
| trols servo motor
TemperatureController Reads thermocouple data; checks target temperatures; trig-
| gers alerts
DataLogger | Manages SD card operations; logs session data; retrieves
| historical logs
UserInterface | Handles Blynk communication; sends temperature data; re-
| ceives user commands

### 12 PACKAGE DIAGRAM

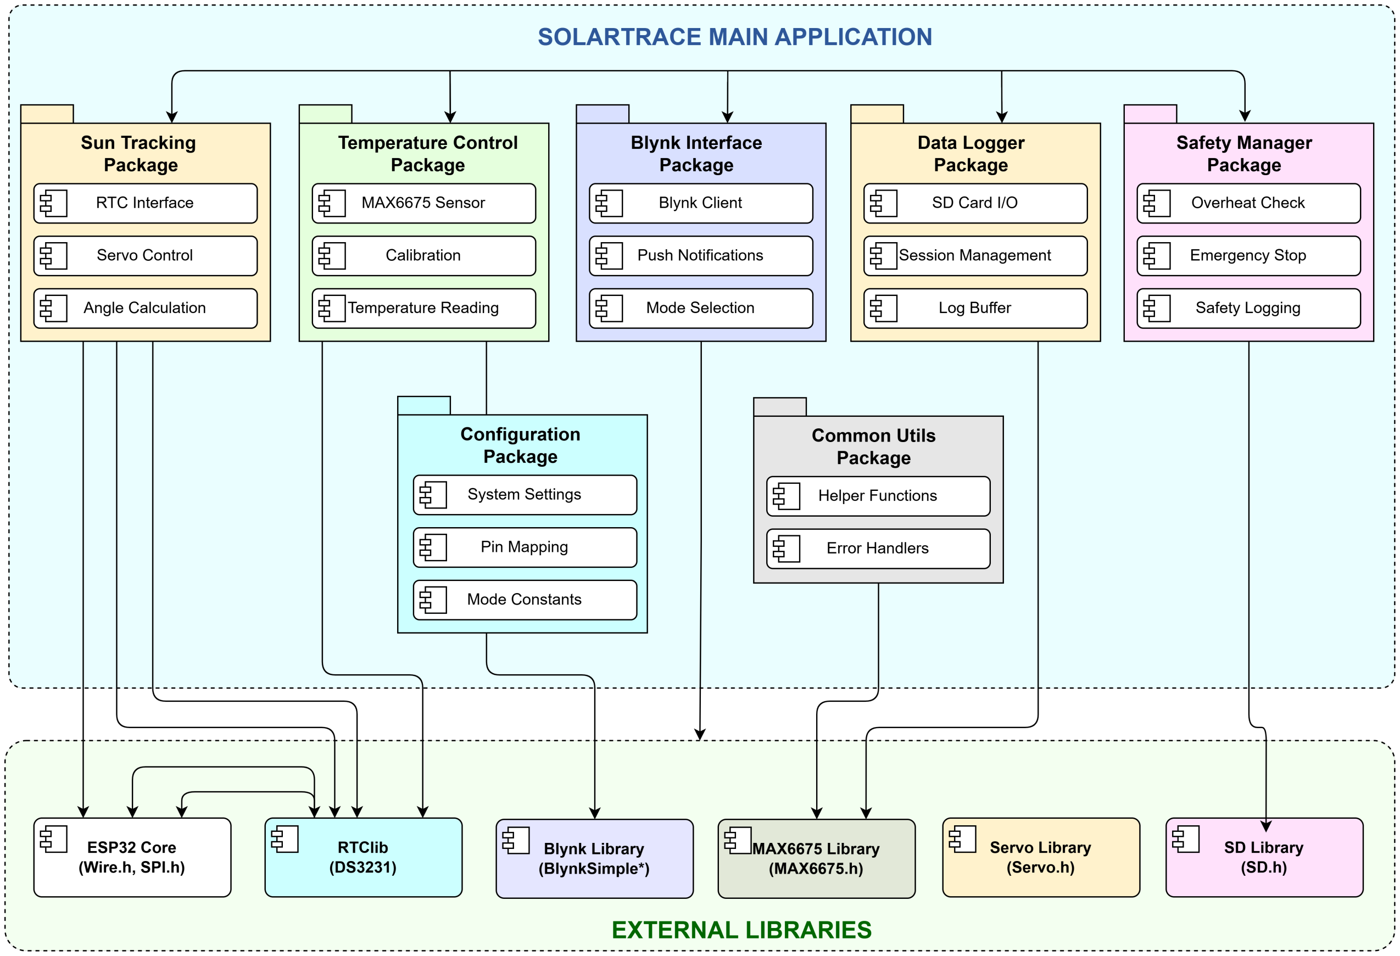
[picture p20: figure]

Figure 14: Package Diagram: Module Organization

### 12.1 Package Descriptions

Table 10: Package Descriptions

Package | Contents
Main Application | Main entry point; initialization; system loop; state manage-
| ment
Tracking | RTC communication; solar angle calculation; servo posi-
| tioning
Sensors | MAX6675 interface; temperature conversion; error han-
| dling
Communication | Blynk integration; push notifications; mode selection; data
| streaming
Data Storage | SD card operations; session creation; data logging; log re-
| trieval

### 13 TECHNICAL SPECIFICATIONS

### 13.1 Hardware Specifications

Table 11: Hardware Technical Specifications

Component | Model | Specifications
Microcontroller | ESP32-DEVKIT | Dual-core Xtensa LX6, 240MHz, 520KB
| | SRAM, 4MB Flash, Wi-Fi/BLE
RTC Module | DS3231 | ±2ppm accuracy, I2C interface, battery backup,
| | 0-70°C range
Temperature Sensor | MAX6675 | 12-bit resolution, 0.25°C accuracy, 0-500°C
| | range, SPI interface
Thermocouple | K-Type | Chromel-Alumel, -200 to 1350°C range, 41
| | µV/°C sensitivity
Servo Motor | MG995 | 15kg/cm torque, 0.2s/60°speed, 4.8-7.2V, metal
| | gears
Parabolic Dish | Custom | 0.9m diameter, aluminum reflector, focal length
| | 0.4-0.5m
Power System | 5V Panel + 18650 5W panel, 3.7V 3000mAh battery, TP4056
| | charger
Data Storage | MicroSD Card | Up to 32GB, FAT32 format, SPI interface

### 13.2 Pin Configuration for ESP32-DEVKIT

Table 12: ESP32-DEVKIT Pin Configuration

ESP32-DEVKIT
Pin
| Function | Component | Notes
GPIO21 | I2C Data (SDA) | DS3231 RTC | 4.7kΩ pull-up required
GPIO22 | I2C Clock (SCL) | DS3231 RTC | 4.7kΩ pull-up required
GPIO13 | PWM Output | MG995 Servo | 50Hz | signal, | 0-
180°control
GPIO15 | SPI Chip Select | MAX6675 | Active low
GPIO14 | SPI Clock | MAX6675
GPIO12 | SPI Data Out | MAX6675
GPIO5 | SPI Chip Select | MicroSD
GPIO18 | SPI Clock | MicroSD
GPIO23 | SPI Master Out | MicroSD
GPIO19 | SPI Master In | MicroSD
VIN (5V) | Power Input | MG995 Servo | 5V power
3.3V | Power Output | RTC, MAX6675, SD | 3.3V power
GND | Ground | All | Common ground

### 13.3 Tracking Algorithm Specification

Table 13: Tracking Algorithm Parameters

Parameter | Value
Latitude | 4.85°N (Juba, South Sudan)
Sunrise Time | 6:30 AM (local)
Sunset Time | 6:00 PM (local)
Total Daylight | 690 minutes (11.5 hours)
Sun Movement | 15°per hour
Servo Adjustment Frequency | Every 10 minutes
Servo Step Angle | 2.5°per step
Total Tracking Range | 0°to 120°
Servo Update Formula | angle = (minutes since sunrise / total daylight) × 120°

### 13.4 Cooking Mode Specifications

Table 14: Cooking Mode Parameters

Mode | Code | Target Temperature | Special Conditions
Cooking | 0 | 80-100°C | General cooking of staple foods
Sterilization | 1 | 120°C | Hold for 20 minutes; completion alert
Boil Water | 2 | 100°C | Alert when reached; no hold required
Warming | 3 | 70°C | Maintain temperature; keep warm
Safety Override | 4 | N/A | Move reflector to idle; 130°C trigger

### 13.5 Communication Protocol

Table 15: Blynk IoT Communication Parameters

Parameter | Value
Platform | Blynk IoT
Protocol | TCP/IP over Wi-Fi
Data Rate | Configurable (default: 1 second interval)
Virtual Pins | V0-Mode | Selection, | V1-Temperature, | V2-
Notifications, V3-Logging, V4-Safety
Authentication | Auth Token from Blynk App
Push Notifications | Blynk.notify() function
Offline Operation | SD card logs; sync when reconnected

### 14 INTERFACE DESIGN

### 14.1 Blynk Dashboard Layout

Table 16: Blynk Widget Configuration

Widget | Pin | Function
Dropdown | V0 | Mode selection: Cooking, Sterilization, Boil Water, Warming
Gauge | V1 | Real-time temperature display (0-150°C)
Notification | V2 | Push notification alerts
Label | V3 | Session logging status display
Button | V4 | Emergency stop/override
Label | V5 | CO2 savings estimate display

### 14.2 User Interaction Flow

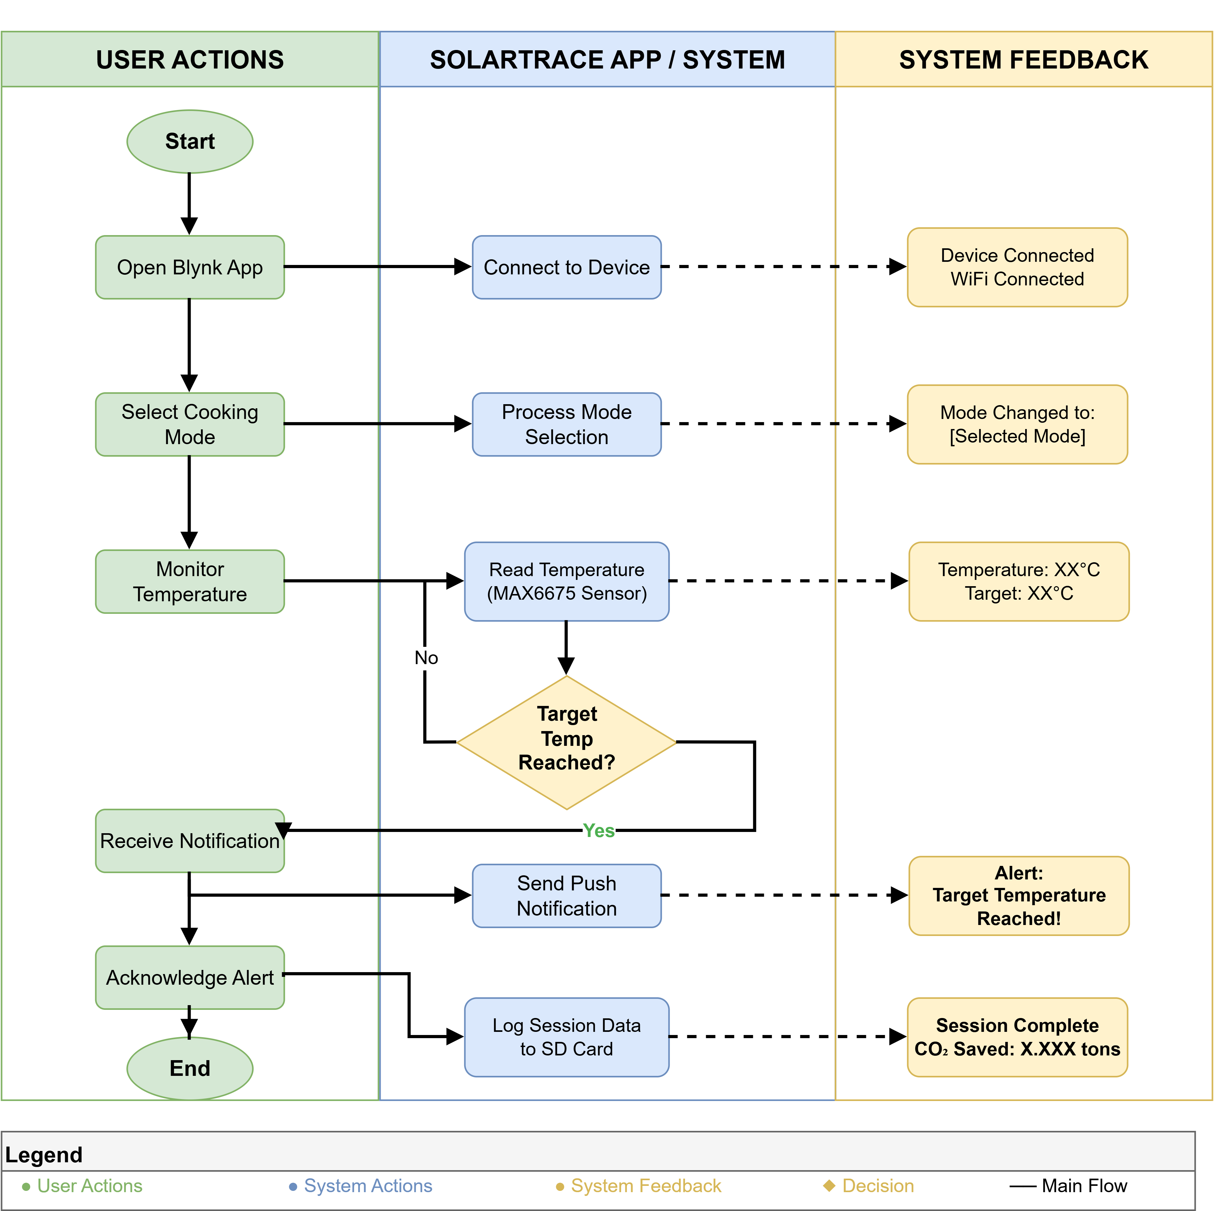
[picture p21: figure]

Figure 15: User Interaction Flow

### 15 SUMMARY AND NEXT STEPS

### 15.1 Design Summary

This chapter has presented the complete technical architecture and design for the SolarTrace system, including:

- Alternative Systems Analysis: Validating the SolarTrace approach against existing solutions
- ESP32-DEVKIT Microcontroller: Detailed pinout, specifications, and features
- System Schematic: Complete wiring diagram and component connections
- Parabolic Dish: Design, geometry, specifications, and construction
- System Architecture: Three-tier architecture with physical, control, and application layers
- UML Diagrams: Context, data flow, use case, activity, sequence, class, and package diagrams
- Technical Specifications: Detailed component, pin, algorithm, and mode specifications
- Interface Design: Blynk-based mobile application with intuitive controls

### 15.2 ESP32-DEVKIT Advantages for SolarTrace

Table 17: ESP32-DEVKIT Advantages

Feature | Benefit for SolarTrace
Built-in WiFi | Enables IoT connectivity without additional modules
Built-in BLE | Supports Bluetooth for local configuration
Dual-core Processor | Handles tracking and communication simultaneously
Low Cost | Under $25, suitable for rural deployment
Large Community | Extensive documentation and libraries available
Low Power Consump- tion | Suitable for solar/battery operation

### 15.3 NEXT STEPS: Week 3 - Core Development

With the design phase complete, the team will proceed to Week 3: Core Development, which includes:

1. Setting up the development environment (Arduino IDE, libraries, Blynk)

2. Implementing RTC initialization and time retrieval
3. Coding servo positioning logic based on time-of-day calculations
4. Integrating temperature monitoring with MAX6675
5. Testing each component independently
6. Basic system integration

### 15.4 Design Decision Justification

Table 18: Key Design Decisions and Justifications

Decision | Justification

RTC-based tracking
vs. Light sensors

More reliable in cloudy conditions; lower cost; predictable operation
ESP32-DEVKIT vs.
Arduino Nano

Built-in Wi-Fi reduces external components; more processing power; development board ready
Blynk platform | Free tier suitable for prototype; easy to use; push no-
tification support
K-type thermocouple

Wide temperature range; suitable for hightemperature cooking
SD card logging | Offline capability essential for areas with limited in-
ternet connectivity
MG995 servo | High torque sufficient for 0.9m reflector; metal gears
for durability

### 16 REFERENCES

### References

[1] A. J. Abid, “Arduino based blind solar tracking controller,” IETI Trans. Comput., vol. 3, no. 1, pp. 16-30, 2017.
[2] A. Mahmood et al., “Enhancement of the hybrid solar cooker performance by solar tracking,” AIP Conf. Proc., vol. 3282, p. 050004, 2025.
[3] M. Rashid et al., “A sustainable energy management evaluation of a hybrid solar geyser-stove system,” Results Eng., 2025.
[4] J. A. Duffie and W. A. Beckman, Solar Engineering of Thermal Processes, 3rd ed. Hoboken, NJ: Wiley, 2006.
[5] O. Eboh, C. Nwosu, and I. Okonkwo, “Design and manufacturing of a single axis solar tracking system,” Nigerian J. Eng. Sci. Res., 2025.
[6] G. Shukla et al., “IoT-enabled solar PV systems: Real-time monitoring and efficiency optimization,” Results Eng., 2025.
[7] R. Swarnkar et al., “Multi-objective genetic algorithm in optimization of performance analysis of IoT based temperature monitoring,” Int. J. Interact. Des. Manuf., vol. 20, no. 6, p. 3173, 2024.
[8] S. A. Ogalo and K. V. Rop, “Analysis of cooking fuels and cooking energy demand in rural households,” Strathmore University, Nairobi, Kenya, 2024.
[9] M. M. Alenazi, “IoT and energy,” in IntechOpen, 2023.
[10] Espressif Systems, “ESP32 Series Datasheet,” 2024.

### Document Control

Version | Changes | Date | Author
1.0 | Initial Week 2 submission package | July 31, 2026 | Team South Sudan
1.1 | Added ESP32 pinout, | system
| schematic, wiring diagram | July 31, 2026 | Team South Sudan
1.2 | Updated to ESP32-DEVKIT, added specifications table
August | 1,
| | 2026 | Team South Sudan
1.3 | Removed duplicate pin configura- tion table
August | 2,
| | 2026 | Team South Sudan
1.4 | Added Parabolic Dish section with figures
August | 2,
| | 2026 | Team South Sudan

Document Owner: SolarTrace Team - South Sudan Distribution: UbuntuNet Alliance Mentor Classification: Submission Document

This document represents the complete Week 2 submission package for the UbuntuNet Alliance Women Hackathon 2026.

TEAM SOUTH SUDAN - SOLARTRACE Harnessing the sun for a sustainable future

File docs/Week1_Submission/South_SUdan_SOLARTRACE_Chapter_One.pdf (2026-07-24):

## UbuntuNet Alliance Women Hackathon 2026

### Phase I - Week 1 Submission

# SOLARTRACE

## Chapter 1: Introduction

Team South Sudan

Name | Role
Alek Madut Malual | Lead Developer
Clementina Agiu Gual Koch | UI/UX & Documentation
Abuk Santino Garang Chan | Testing & Logistics

Submission Date: July 24, 2026

Document Type: Week 1 Submission Package Includes: Background, Problem Statement, Novelty, Objectives, Research Questions, Significance, Delimitations

SolarTrace - South Sudan | Chapter 1: Introduction
1 | July 24, 2026

Contents

1 BACKGROUND TO THE STUDY | 4
2 STATEMENT OF THE PROBLEM | 8
3 NOVELTY AND INNOVATION | 10
4 PROTOTYPE OBJECTIVES | 12
5 PROTOTYPE RESEARCH QUESTIONS | 14

6 SIGNIFICANCE OF THE STUDY | 15
7 DELIMITATIONS OF THE STUDY | 17
8 REFERENCES | 19

List of Figures

1 | Electricity Access Rates in Select Countries | 4
2 | Consequences of Biomass Dependence | 5
3 | Hybrid Solar Cooker Performance with Tracking [7] | 7
4 | SolarTrace System Architecture | 13
5 | SolarTrace Alignment with Sustainable Development Goals | 16

List of Tables

1 | Biomass Dependence in South Sudan - Key Statistics | 4
2 | South Sudan - Key Contextual Statistics | 6
3 | Comparison of Existing Solar Cooker Systems vs. SolarTrace | 9
4 | SolarTrace Innovation Comparison | 10
5 | Prototype Objectives and Corresponding Technologies | 12
6 | Stakeholder Impact Matrix | 15
7 | Technical Specifications and Delimitations | 17

### 1 BACKGROUND TO THE STUDY

### 1.1 The Energy Access Crisis in Sub-Saharan Africa

Sub-Saharan Africa faces the most severe energy access deficit globally. According to the

International Energy Agency [1], only 48% of the population has access to electricity, with

rural areas experiencing significantly lower rates. South Sudan, the project’s target country, has

one of the lowest electricity access rates globally at approximately 7%.

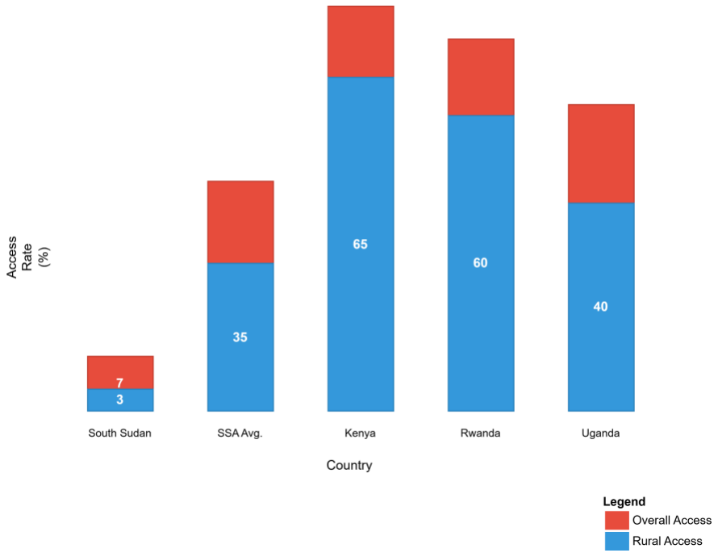
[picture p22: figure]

Figure 1: Electricity Access Rates in Select Countries

### 1.2 Biomass Dependence and Its Consequences

Across Sub-Saharan Africa, over 80% of households depend on biomass—firewood and char-

coal—for cooking meals, boiling water, and sterilizing tools. This dependence has multiple

cascading consequences.

Table 1: Biomass Dependence in South Sudan - Key Statistics

Indicator | Value
Households dependent on biomass | >80%
Average monthly fuel expenditure | USD 30-50
Daily time spent collecting firewood | 4-6 hours
Forest cover loss since 2000 | ∼20%
Annual CO2 per household | ∼1.0 ton

### 1.2.1 Environmental Impact

The State of the World’s Forests 2024 [2] reports that over 4.5 million hectares of forest are

lost annually in Africa, with South Sudan losing approximately 20% of its forest cover since

2000. The IPCC [3] notes that each household using biomass contributes approximately 1.0-

ton CO2 annually, accelerating climate change and biodiversity loss.

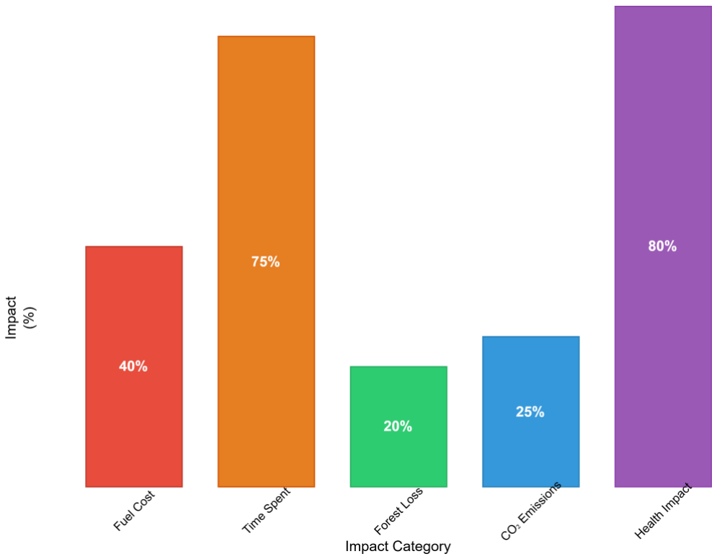
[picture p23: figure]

Figure 2: Consequences of Biomass Dependence

### 1.2.2 Economic Burden

Ndung’u and Mutua [4] document that typical families spend USD 30-50 monthly on charcoal

or firewood, representing a significant portion of household income in rural areas. Small rural

clinics often spend over USD 100 monthly on kerosene for sterilization. Women and children

spend 4-6 hours daily collecting firewood, reducing time for education and income-generating

activities.

### 1.2.3 Health Impact

The World Health Organization [5] reports that indoor air pollution causes 3.2 million pre-

mature deaths annually, with women and children disproportionately affected. Respiratory

diseases, eye infections, and burns are common, with children under five being particularly

vulnerable.

### 1.3 South Sudan Context

South Sudan presents a unique set of challenges and opportunities for solar cooking:

- Abundant solar resource: The country receives an average of 5-7 kWh/m²/day
- Post-conflict context: Over 2 million internally displaced persons and 2.2 million refugees
- Fragile health system: Many rural clinics lack reliable electricity for sterilization
- Gender inequality: Women bear the primary burden of fuel collection
- Emerging ICT infrastructure: Growing mobile phone penetration creates opportunities for IoT

Table 2: South Sudan - Key Contextual Statistics

Indicator | Value
Electricity Access Rate | 7%
Daily Solar Radiation | 5-7 kWh/m²/day
Household Fuel Expenditure | USD 30-50/month
Forest Cover Loss (2000-2020) | ∼20%
Internally Displaced Persons | >2 million
Mobile Phone Penetration | ∼40%

### 1.4 Solar Cooking Technologies

### 1.4.1 The Problem with Manual Solar Cookers

While solar cookers offer a clean alternative to biomass, their effectiveness is limited by:

- Need for constant manual repositioning: Users must adjust the cooker every 30-60 minutes to track the sun [6]
- Temperature fluctuations: Without consistent adjustment, cooking temperatures decline by 20-30°C [7]
- Poor user adoption: The inconvenience of manual tracking leads to abandonment
- Limited functionality: Many manual cookers cannot achieve or maintain temperatures required for sterilization (120°C)

### 1.4.2 Advances in Solar Cooking Technology

Recent research has focused on addressing these limitations:

- Automatic tracking systems: Using motors and sensors to follow the sun [8, 6]
- IoT integration: Remote monitoring and control via mobile applications [9, 10]
- Thermal energy storage: Extending cooking beyond daylight hours
- Hybrid designs: Combining solar with alternative heat sources [7]

Mahmood et al. [7] demonstrated that tracked solar cookers achieve significantly higher

temperatures, with their hybrid solar cooker achieving 95°C with tracking compared to 86°C

without tracking.

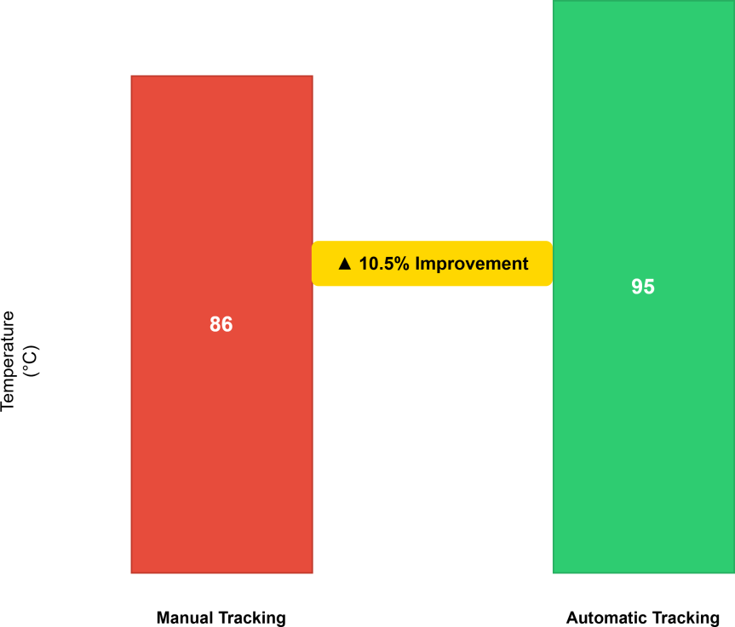
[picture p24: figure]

Figure 3: Hybrid Solar Cooker Performance with Tracking [7]

### 2 STATEMENT OF THE PROBLEM

### 2.1 Core Problem

Rural and peri-urban communities in South Sudan lack access to clean, reliable, and

affordable cooking energy, leading to deforestation, health crises, and economic hardship,

while existing solar cooking solutions remain underutilized due to the need for constant

manual tracking.

### 2.2 Problem Breakdown

1. Energy Access Crisis
- 93% of the population lacks electricity access [1]
- 80%+ of households depend on biomass (firewood/charcoal) [2]
- Fuel collection consumes 4-6 hours daily, primarily by women and children [5]
2. Environmental Degradation
- South Sudan has lost 20% of forest cover since 2000 [2]
- Deforestation driven by charcoal production and firewood collection
- Each household contributes 1.0-ton CO2 annually [3]
3. Health Crisis
- Indoor air pollution from biomass causes 3.2 million premature deaths globally [5]
- Women and children are disproportionately affected in South Sudan
- Rural clinics lack fuel for sterilization of surgical instruments
4. Economic Burden
- Households spend USD 30-50 monthly on cooking fuels [4]
- Rural clinics spend USD 100+ monthly on kerosene
- Fuel collection reduces time for education and income generation
5. Technology Adoption Barriers
- Manual solar cookers require repositioning every 30-60 minutes
- Without consistent adjustment, temperatures decline by 20-30°C [7]
- Poor user adoption due to inconvenience and limited functionality

### 2.3 The Research Gap

While automatic tracking systems have been developed in controlled settings, they are not

widely available or affordable in South Sudan. IoT integration for remote monitoring and

control of solar cookers is limited in the region. There is no documented RTC-based tracking

system designed specifically for the South Sudan context, and rural clinics lack access to clean,

fuel-free sterilization technology.

Table 3: Comparison of Existing Solar Cooker Systems vs. SolarTrace

Feature | Existing Systems | SolarTrace
Sun Tracking | Manual (30-60 min intervals) | Automatic (RTC-based, 10 min)
IoT Integration | Limited or none | Full Blynk integration
Mobile Application | Rare | Comprehensive mode selection
Data Logging | Not available | SD card + cloud logging
Sterilization Mode | Not supported | 120°C for 20 minutes
Safety Mechanism | None | 130°C automatic shutdown
Target Region | Global focus | Designed for South Sudan

### 2.4 Consequences of Inaction

If this problem is not addressed:

- Deforestation will continue, accelerating climate change
- Households will remain trapped in poverty due to fuel expenditure
- Women and children will continue to suffer health impacts and lost opportunities
- Rural clinics will struggle to provide safe surgical care
- South Sudan will miss its climate mitigation and adaptation goals

### 3 NOVELTY AND INNOVATION

### 3.1 What Makes SolarTrace Novel

The innovation of SolarTrace lies in the integration of multiple technologies into a cohesive, low-cost system designed specifically for the South Sudan context:

1. First RTC-Based Tracking System for South Sudan: No documented system exists that uses a Real-Time Clock module for automatic sun tracking specifically calibrated for South Sudan’s latitude (4.85°N)
2. Integrated IoT and Mobile Monitoring: Unlike manual solar cookers, SolarTrace provides real-time temperature monitoring and push notifications via the Blynk platform
3. Dual-Purpose Design: The system supports both cooking and sterilization applications, addressing both household and clinic needs
4. Offline Data Logging: SD card storage ensures data collection even in areas without internet connectivity
5. Low-Cost Implementation: Bill of Materials under USD 300 makes the system accessible for local manufacturing

### 3.2 Comparison with Existing Work

Table 4: SolarTrace Innovation Comparison

Aspect | Abid (2017) | Mahmood
| | (2025)
| | et | al. SolarTrace
Tracking Type | Dual-axis | Hybrid (box + tube) | Single-axis | RTC-
| | | based
IoT Platform | Not specified | Not specified | Blynk
Mobile App | No | No | Yes
Sterilization Mode | No | No | Yes (120°C/20 min)
Safety Mechanism | No | No | Yes (130°C shut-
| | | down)
Target Region | Generic | Iraq | South Sudan
Cost | Not specified | Not specified | < USD 300

### 3.3 Expected Improvements

Based on literature estimates [11, 12], SolarTrace is expected to achieve:

- 40-60% reduction in household cooking fuel costs (literature-based estimate)

- 30-40% improvement in cooking temperature consistency compared to manual tracking
- USD 100+/month savings for rural clinics through fuel-free sterilization
- 1.0-ton CO2 savings per household annually (based on IPCC [3] estimates)
- 4-6 hours/day of time freed for women and children

### 4 PROTOTYPE OBJECTIVES

### 4.1 General Objective

To develop and pilot a smart, IoT-connected parabolic solar cooker with time-based

automatic sun tracking that reduces household cooking energy costs by at least 40%

compared to charcoal.

### 4.2 Specific Objectives

1. Implement RTC-triggered servo movement every 10 minutes based on pre-calculated solar angles for the local latitude (4.85°N), achieving tracking accuracy within ±5°
2. Develop a user-friendly mobile application using Blynk that allows selection of cooking modes and provides real-time temperature monitoring
3. Deliver push notifications when target temperatures are achieved or when unexpected temperature drops occur
4. Record each cooking session, including duration, peak temperature, and estimated CO2 savings, with offline SD card storage capability
5. Automatically tilt the reflector away from the sun when temperatures exceed 130°C to prevent equipment damage and ensure user safety

Table 5: Prototype Objectives and Corresponding Technologies

Objective | Technology | Reference
RTC-based sun tracking | DS3231 RTC, MG995 Servo | [8, 13]
Mobile application | Blynk IoT Platform | [9]
Push notifications | Blynk Notifications | [10]
Data logging | MicroSD card module | [9]
Temperature monitoring | MAX6675 K-type thermocouple | [9]

### 4.3 System Architecture

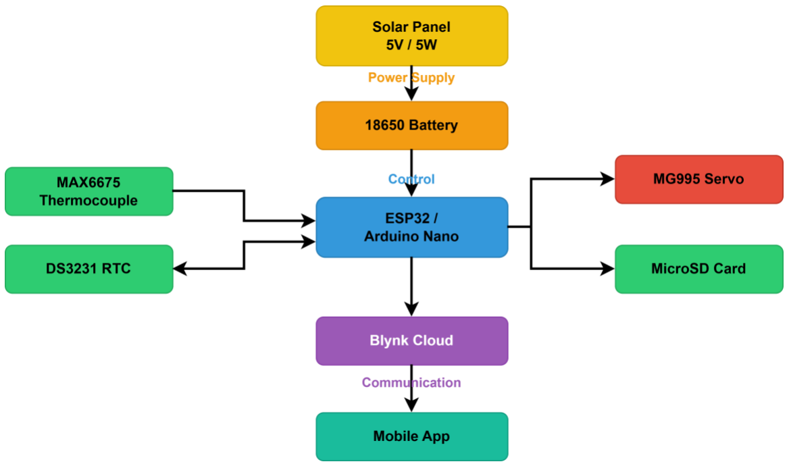
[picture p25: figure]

Figure 4: SolarTrace System Architecture

### 5 PROTOTYPE RESEARCH QUESTIONS

1. Tracking Accuracy: How accurate is the time-based tracking algorithm for Juba, South Sudan (4.85°N) when compared to optimal solar positioning?
2. User Interface Design: How can a Blynk-based mobile interface be designed to provide intuitive control and monitoring for users with basic digital literacy?
3. Notification Effectiveness: Can IoT-based push notifications improve user experience and reduce the risk of undercooked food or failed sterilization?
4. Data Logging Capability: What isthe effectiveness of an SD card-based logging system for capturing and analyzing cooking data in off-grid environments?
5. Safety Mechanism Reliability: Does the safety mechanism trigger reliably at 130°C and prevent overheating in all operational conditions?

### 6 SIGNIFICANCE OF THE STUDY

### 6.1 Who Benefits?

Table 6: Stakeholder Impact Matrix

Stakeholder | Primary Benefit | Scale
Rural Households | Reduced fuel expenditure (40-60%), reduced smoke
exposure
Women & Children Reduced time collecting fuel (4-6 hours/day), improved health
Rural Clinics | Fuel-free | sterilization, | cost | savings | (USD
100+/month)
Community | Reduced deforestation, | improved environmental
| health

Direct

Direct

Direct

Indirect

Government | Progress toward climate goals (NDCs) | Indirect
Environment | Reduced CO2 emissions (1.0 ton/household/year) | Global

### 6.2 Technical Significance

- First RTC-based automatic tracking system designed for South Sudan
- Integration of IoT (Blynk) for remote monitoring and control
- Open-source documentation for replication and adaptation
- Low-cost design (BOM ¡ USD 300) suitable for local manufacturing

### 6.3 Scientific Significance

- Contributes to the growing body of research on IoT in renewable energy [14, 15]
- Provides empirical data on solar cooking in a post-conflict context
- Advances understanding of technology adoption in low-resource settings
- Documents the feasibility of solar sterilization in rural clinics [16]

### 6.4 Policy Significance

- Supports South Sudan’s Nationally Determined Contributions (NDCs) under the Paris Agreement
- Aligns with SDG 7 (Affordable and Clean Energy), SDG 13 (Climate Action), and SDG

5 (Gender Equality)

- Provides evidence for renewable energy policy development
- Demonstrates the potential of ICT in climate adaptation

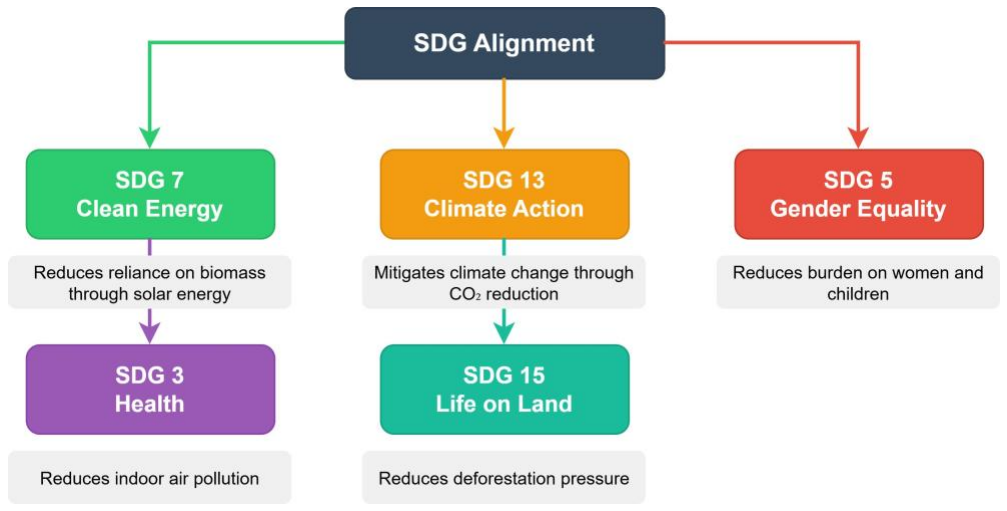
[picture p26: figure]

Figure 5: SolarTrace Alignment with Sustainable Development Goals

### 7 DELIMITATIONS OF THE STUDY

### 7.1 Geographic Scope

- Primary focus: Juba, South Sudan (4.85°N latitude)
- Reason: Capital city with existing ICT infrastructure and research partners
- Exclusion: Other regions of South Sudan (pending validation)

### 7.2 Technical Scope

- Prototype only: Designed for demonstration and pilot testing
- Hardware: Parabolic reflector (0.9m), Arduino Nano/ESP32, DS3231 RTC, MAX6675 thermocouple, MG995 servo
- Software: C++ (Arduino IDE), Blynk IoT platform
- Exclusion: Large-scale production or commercialization (beyond hackathon scope)

Table 7: Technical Specifications and Delimitations

Component | Specification | Limitation
Parabolic Reflector | 0.9m diameter | Fixed size, not scalable
Microcontroller | Arduino Nano/ESP32 | Limited processing power
RTC Module | DS3231 | Requires battery backup
Temperature Sensor | MAX6675 K-type | 0-500°C range
Actuator | MG995 Servo | Torque limited to 15kg/cm

### 7.3 Functional Scope

- Cooking modes: Four modes (cooking, sterilization, boiling, warming)
- Temperature range: 70-130°C (with safety cut-off at 130°C)
- Application: Cooking staple foods, boiling water, sterilization
- Exclusion: Space heating, water heating for bathing, electricity generation

### 7.4 Temporal Scope

- Prototype development: July-August 2026 (Hackathon Phase I)
- Testing: September 2026 (Phase II preparation)
- Evaluation: October 2026 (Phase II - Malawi)
- Exclusion: Long-term impact assessment (beyond hackathon timeline)

### 7.5 User Scope

- Primary users: Rural and peri-urban households, small rural clinics
- User profile: Basic digital literacy assumed
- Exclusion: Large-scale institutional or commercial cooking

### 7.6 Limitations (Acknowledged Constraints)

- Weather dependence: System requires adequate sunlight (cloudy days affect performance)
- Power supply: Requires 5V solar panel with battery backup
- Time constraints: Hackathon duration limits extensive user testing
- Resource constraints: No funding for large-scale field trials
- Technical expertise: Team members have varying programming proficiency

### 8 REFERENCES

References

[1] IEA, Africa Energy Outlook 2023. Paris, France: International Energy Agency, 2023.
[2] FAO, State of the World’s Forests 2024. Rome, Italy: Food and Agriculture Organization, 2024.
[3] IPCC, Climate Change 2023: Synthesis Report. Geneva, Switzerland: Intergovernmental Panel on Climate Change, 2023.
[4] J. Ndung’u and J. Mutua, “The economic burden of cooking fuels in rural Kenya,” Afr. J. Energy Econ., 2022.
[5] World Health Organization, Household Air Pollution and Health. Geneva, Switzerland: WHO, 2023.
[6] R. Abu-Malouh, A. Al-Salaymeh, and H. Al-Masri, “Design, construction and operation of spherical solar cooker with automatic sun tracking system,” Energy Convers. Manage., vol. 52, no. 1, pp. 615-620, 2011.
[7] A. Mahmood et al., “Enhancement of the hybrid solar cooker performance by solar tracking,” AIP Conf. Proc., vol. 3282, p. 050004, 2025.
[8] A. J. Abid, “Arduino based blind solar tracking controller,” IETI Trans. Comput., vol. 3, no. 1, pp. 16-30, 2017.
[9] M. Rashid et al., “A sustainable energy management evaluation of a hybrid solar geyserstove system,” Results Eng., 2025.
[10] R. Swarnkar et al., “Multi-objective genetic algorithm in optimization of performance analysis of IoT based temperature monitoring,” Int. J. Interact. Des. Manuf., vol. 20, no. 6, p. 3173, 2024.
[11] S. Verma et al., “Socio-economic impact of solar cooking technologies,” Eng. Rep., 2025.
[12] S. A. Ogalo and K. V. Rop, “Analysis of cooking fuels and cooking energy demand in rural households,” Strathmore University, Nairobi, Kenya, 2024.
[13] O. Eboh, C. Nwosu, and I. Okonkwo, “Design and manufacturing of a single axis solar tracking system,” Nigerian J. Eng. Sci. Res., 2025.
[14] M. M. Alenazi, “IoT and energy,” in IntechOpen, 2023.

[15] G. Shukla et al., “IoT-enabled solar PV systems: Real-time monitoring and efficiency optimization,” Results Eng., 2025.
[16] S. Saleh et al., “Performance and efficiency of an autoclave for solar energy applications in winter and summer in Iraq,” J. Eng. Sci., 2024.
[17] J. A. Duffie and W. A. Beckman, Solar Engineering of Thermal Processes, 3rd ed. Hoboken, NJ: Wiley, 2006.
[18] African Energy Chamber, The State of African Energy 2023.Johannesburg, South Africa: African Energy Chamber, 2023.
[19] Solar Cookers International, “SCI and Root of Generations highlight gender perspectives in solar cooking at COP29,” 2024.
[20] Solar Cookers International, Solar Cooking Basics Manual, n.d.

Document Control

Version | Changes | Date | Author
1.0 | Initial Week 1 submission package | July 24, 2026 | Team South Sudan

Document Owner: SolarTrace Team - South Sudan Distribution: UbuntuNet Alliance Mentor Classification: Submission Document

This documentrepresents the complete Week 1 submission package forthe UbuntuNet Alliance Women Hackathon 2026.

TEAM SOUTH SUDAN - SOLARTRACE Harnessing the sun for a sustainable future

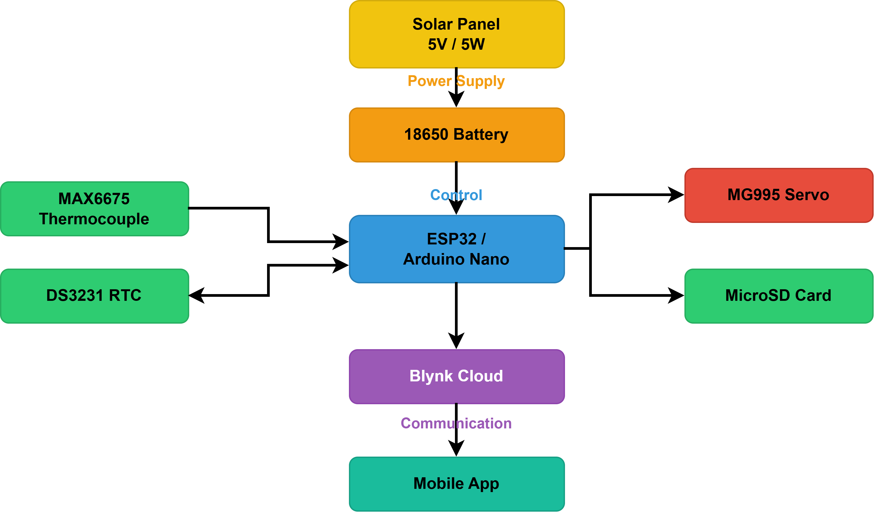
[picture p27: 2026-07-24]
assets/diagrams/fig4_architecture.png

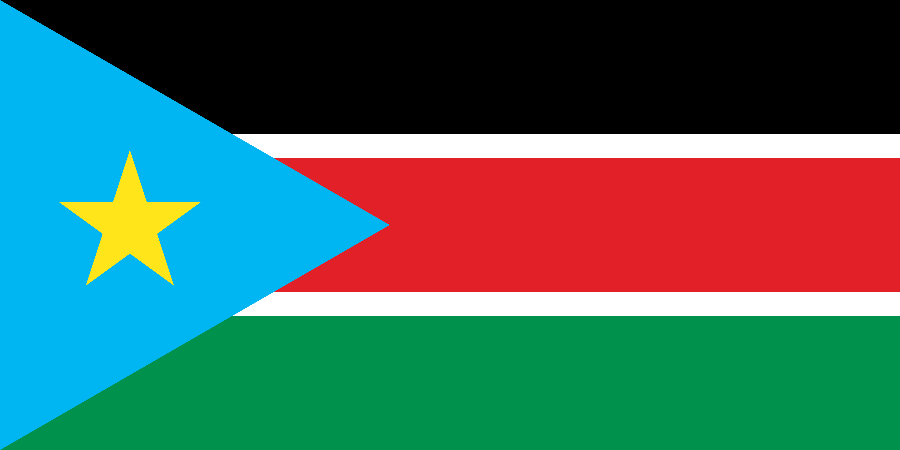
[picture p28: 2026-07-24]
assets/images/south_sudan_flag.png

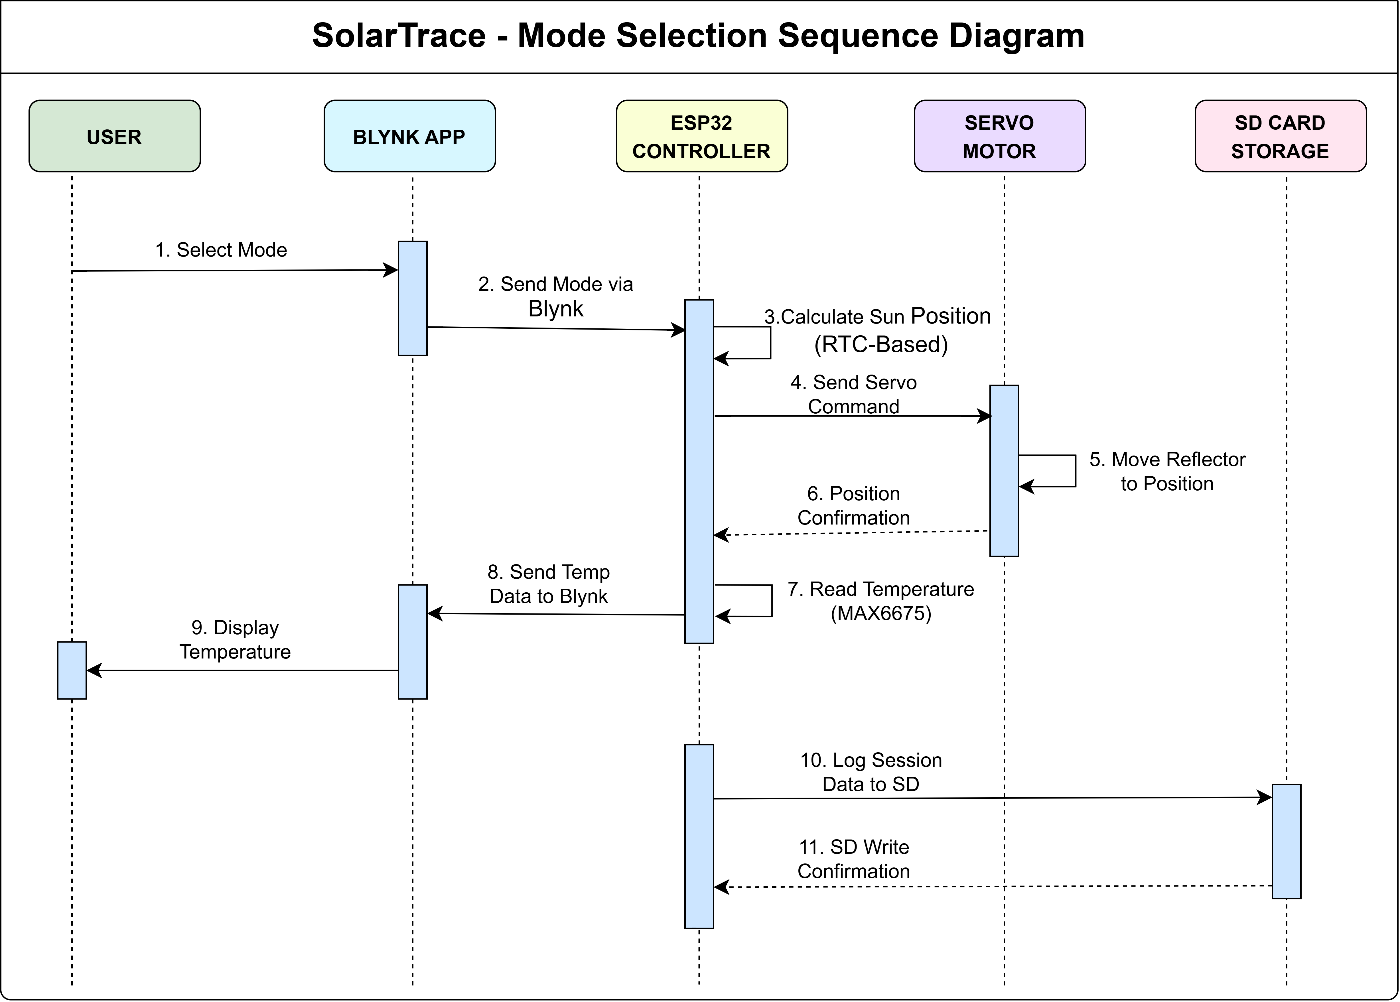
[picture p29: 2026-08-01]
docs/Week2_Submission/UML_Diagrams/SolarTrace - Mode Selection Sequence Diagram (1).png

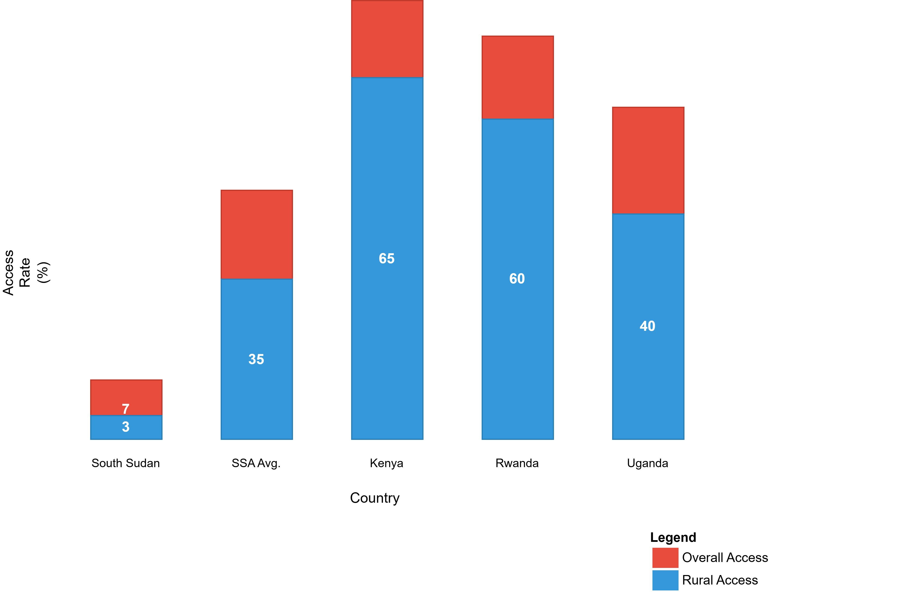
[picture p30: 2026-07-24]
assets/images/fig1_access_rates.png

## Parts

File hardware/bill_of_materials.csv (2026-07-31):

Category | Item | Model/Part | Quantity | Unit Cost (USD) | Total Cost (USD) | Supplier | Status | Notes
Microcontroller | ESP32 Development Board | ESP32-WROOM-32 | 1 | 25.00 | 25.00 | AliExpress/Amazon | Required | Core processor with WiFi/BLE
RTC Module | DS3231 Real-Time Clock | DS3231 | 1 | 10.00 | 10.00 | AliExpress/Amazon | Required | I2C interface with battery backup
Temperature Sensor | MAX6675 Module | MAX6675 | 1 | 15.00 | 15.00 | AliExpress/Amazon | Required | With K-type thermocouple
Thermocouple | K-Type Thermocouple | K-Type | 1 | 8.00 | 8.00 | AliExpress/Amazon | Required | High temperature range (0-500°C)
Servo Motor | MG995 Metal Gear Servo | MG995 | 1 | 20.00 | 20.00 | AliExpress/Amazon | Required | 15kg/cm torque
Parabolic Reflector | Parabolic Dish (0.9m) | Custom | 1 | 80.00 | 80.00 | Local Fabrication | Required | Aluminum coated
SD Card Module | MicroSD Card Module | MicroSD | 1 | 5.00 | 5.00 | AliExpress/Amazon | Required | SPI interface
SD Card | MicroSD Card (16GB) | Class 10 | 1 | 10.00 | 10.00 | AliExpress/Amazon | Required | FAT32 formatted
Solar Panel | 5V 5W Solar Panel | 5W | 1 | 25.00 | 25.00 | AliExpress/Amazon | Required | For off-grid operation
Battery | 18650 Li-ion Battery | 18650 | 1 | 10.00 | 10.00 | AliExpress/Amazon | Required | 3000mAh
Charger Module | TP4056 Charger Module | TP4056 | 1 | 5.00 | 5.00 | AliExpress/Amazon | Required | With protection circuit
Jumper Wires | Jumper Wires (Male-Male) | 20cm | 20 | 0.25 | 5.00 | AliExpress/Amazon | Required | For breadboard connections
Breadboard | 830 Point Breadboard | 830pt | 1 | 5.00 | 5.00 | AliExpress/Amazon | Required | For prototyping
Resistor | 4.7kΩ Resistor (2 pcs) | 1/4W | 2 | 0.25 | 0.50 | AliExpress/Amazon | Required | Pull-up for I2C
Enclosure | Waterproof Enclosure | Custom | 1 | 15.00 | 15.00 | Local | Optional | For outdoor protection
Mounting Hardware | Mounting Brackets | Custom | 1 | 10.00 | 10.00 | Local | Optional | For reflector mounting
USB Cable | USB-A to Micro-B (1m) | 1m | 1 | 3.00 | 3.00 | AliExpress/Amazon | Required | For programming
Power Supply | 5V 2A Power Supply | 5V/2A | 1 | 12.00 | 12.00 | AliExpress/Amazon | Optional | For indoor testing
Soldering Kit | Soldering Iron Kit (60W) | 60W | 1 | 15.00 | 15.00 | AliExpress/Amazon | Required | For permanent connections
Multimeter | Digital Multimeter | DT830 | 1 | 10.00 | 10.00 | AliExpress/Amazon | Required | For testing

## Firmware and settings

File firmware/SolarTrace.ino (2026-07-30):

/*
 * ============================================================================
 * SOLARTRACE - Smart Solar Cooker with RTC-Based Automatic Sun Tracking
 * ============================================================================
 * 
 * Project   : SolarTrace
 * Version   : 1.0
 * Date      : July 2026
 * Team      : South Sudan - UbuntuNet Alliance Women Hackathon 2026
 * 
 * Description:
 * This firmware implements a smart solar cooker with automatic sun tracking
 * using an ESP32 microcontroller, DS3231 RTC module, MAX6675 thermocouple,
 * and MG995 servo motor. The system supports 4 cooking modes and communicates
 * with the Blynk IoT platform for remote monitoring and control.
 * 
 * ============================================================================
 * MODES:
 *   0 - COOKING      : 80-100°C  (General cooking)
 *   1 - STERILIZATION : 120°C    (Hold for 20 minutes)
 *   2 - BOIL_WATER   : 100°C     (Alert when reached)
 *   3 - WARMING      : 70°C      (Keep warm)
 *   4 - SAFETY       : N/A       (Emergency override)
 * ============================================================================
 */

#include <Wire.h>
#include <SPI.h>
#include <RTClib.h>
#include <MAX6675.h>
#include <Servo.h>
#include <SD.h>
#include <BlynkSimpleEsp32.h>
#include <WiFi.h>
#include <EEPROM.h>

// ============================================================================
// CONFIGURATION - WIFI AND BLYNK
// ============================================================================

// WiFi Credentials
const char* ssid     = "YOUR_WIFI_SSID";
const char* password = "YOUR_WIFI_PASSWORD";

// Blynk Authentication Token
char auth[] = "YOUR_BLYNK_AUTH_TOKEN";

// ============================================================================
// BLYNK VIRTUAL PINS
// ============================================================================

#define VP_MODE_SELECT     V0   // Mode selection dropdown
#define VP_TEMPERATURE     V1   // Temperature display gauge
#define VP_NOTIFICATION    V2   // Push notifications
#define VP_LOGGING_STATUS  V3   // Logging status
#define VP_EMERGENCY_STOP  V4   // Emergency stop button
#define VP_CO2_SAVINGS     V5   // CO2 savings display

// ============================================================================
// PIN DEFINITIONS
// ============================================================================

// RTC - I2C (SDA = GPIO21, SCL = GPIO22)
// No additional pins needed for I2C

// MAX6675 Thermocouple
#define THERMO_CS   15      // Chip Select
#define THERMO_SCK  14      // SPI Clock
#define THERMO_SO   12      // SPI Data Out

// MG995 Servo Motor
#define SERVO_PIN   13      // PWM Signal

// MicroSD Card Module (SPI)
#define SD_CS       5       // Chip Select
#define SD_SCK      18      // SPI Clock
#define SD_MOSI     23      // SPI Master Out
#define SD_MISO     19      // SPI Master In

// ============================================================================
// GLOBAL OBJECTS
// ============================================================================

RTC_DS3231 rtc;
MAX6675 thermocouple(THERMO_SCK, THERMO_CS, THERMO_SO);
Servo servoMotor;
File logFile;

// ============================================================================
// CONSTANTS AND MACROS
// ============================================================================

// Solar Parameters (Juba, South Sudan - 4.85°N)
#define LATITUDE               4.85
#define SUNRISE_TIME           390     // 6:30 AM in minutes from midnight
#define SUNSET_TIME            1080    // 6:00 PM in minutes from midnight
#define TOTAL_DAYLIGHT         690     // 11.5 hours in minutes
#define SUN_MOVEMENT_PER_HOUR  15.0    // Degrees per hour
#define SERVO_STEP_INTERVAL    10      // Minutes between servo adjustments
#define SERVO_STEP_ANGLE       2.5     // Degrees per step

// Temperature Constants
#define MAX_SAFE_TEMP          130.0   // Maximum safe temperature (°C)
#define TEMP_READ_INTERVAL     500     // Milliseconds between temp readings
#define STERILIZATION_TEMP     120.0   // Sterilization target temperature
#define STERILIZATION_HOLD     20      // Minutes to hold sterilization temp
#define BOIL_TEMP              100.0   // Boiling point
#define WARMING_TEMP           70.0    // Warming target temperature

// Mode Constants
#define MODE_IDLE               -1
#define MODE_COOKING            0
#define MODE_STERILIZATION      1
#define MODE_BOIL_WATER         2
#define MODE_WARMING            3
#define MODE_SAFETY             4

// State Constants
#define STATE_IDLE              0
#define STATE_RUNNING           1
#define STATE_SAFETY            2
#define STATE_ERROR             3

// SD Card Constants
#define LOG_INTERVAL            30000   // 30 seconds between log entries
#define MAX_LOG_BUFFER          10

// ============================================================================
// GLOBAL VARIABLES
// ============================================================================

// System State
int currentMode = MODE_IDLE;
int systemState = STATE_IDLE;
float targetTemperature = 0.0;
float currentTemperature = 0.0;
bool isSafetyActive = false;
bool isHeating = false;
bool isLogging = false;
bool isSterilizing = false;

// Timing Variables
unsigned long lastTempRead = 0;
unsigned long lastLogEntry = 0;
unsigned long sterilizationStartTime = 0;
unsigned long lastServoMove = 0;

// Session Variables
String sessionID = "";
int sessionCount = 0;
float maxTempReached = 0.0;
float co2Saved = 0.0;
int cookingTimeMinutes = 0;

// Log Buffer
String logBuffer[MAX_LOG_BUFFER];
int logBufferIndex = 0;

// ============================================================================
// FUNCTION PROTOTYPES
// ============================================================================

void setupSystem();
void setupRTC();
void setupSDCard();
void setupBlynk();
void setupServo();

void loopSystem();
void handleModeExecution();
void handleSafetyCheck();
void handleTemperatureMonitoring();
void handleServoPositioning();

float calculateSunAngle();
float readTemperature();
void moveServoToAngle(float angle);
void logData(float temp, int mode);
void flushLogBuffer();

void engageSafetyMode();
void disengageSafetyMode();
void emergencyStop();

void startSterilization();
void checkSterilizationComplete();

void sendNotification(String message);
void updateBlynkDashboard();

String generateSessionID();

// ============================================================================
// BLYNK WIDGET HANDLERS
// ============================================================================

/**
 * Blynk Widget: Mode Selection (V0)
 * Called when user selects a mode from the Blynk dropdown
 */
BLYNK_WRITE(VP_MODE_SELECT) {
    int mode = param.asInt();
    if (mode >= MODE_COOKING && mode <= MODE_WARMING) {
        currentMode = mode;
        setMode(mode);
        Blynk.virtualWrite(VP_LOGGING_STATUS, "Mode: " + String(mode));
        sendNotification("Mode changed to: " + getModeName(mode));
    }
}

/**
 * Blynk Widget: Emergency Stop (V4)
 * Called when user presses the emergency stop button
 */
BLYNK_WRITE(VP_EMERGENCY_STOP) {
    if (param.asInt() == 1) {
        emergencyStop();
        Blynk.virtualWrite(VP_EMERGENCY_STOP, 0);  // Reset button
    }
}

// ============================================================================
// MAIN SETUP FUNCTION
// ============================================================================

void setup() {
    // Initialize Serial
    Serial.begin(115200);
    Serial.println("\n\n========================================");
    Serial.println("  SOLARTRACE - Smart Solar Cooker");
    Serial.println("  Team South Sudan - Hackathon 2026");
    Serial.println("========================================\n");
    
    // Setup all subsystems
    setupSystem();
    setupRTC();
    setupSDCard();
    setupServo();
    setupBlynk();
    
    // Generate session ID
    sessionID = generateSessionID();
    
    // Initial servo position (sunrise position)
    moveServoToAngle(0);
    
    // Set initial state
    systemState = STATE_IDLE;
    currentMode = MODE_IDLE;
    
    // Log startup
    logData(0, MODE_IDLE);
    
    Serial.println("SolarTrace initialized successfully!");
    Serial.println("Session ID: " + sessionID);
    Serial.println("Waiting for mode selection...\n");
    
    // Send startup notification
    sendNotification("SolarTrace system ready");
}

// ============================================================================
// MAIN LOOP FUNCTION
// ============================================================================

void loop() {
    // Run Blynk
    Blynk.run();
    
    // Get current time
    DateTime now = rtc.now();
    
    // ========================================
    // 1. TEMPERATURE MONITORING
    // ========================================
    if (millis() - lastTempRead >= TEMP_READ_INTERVAL) {
        lastTempRead = millis();
        currentTemperature = readTemperature();
        
        // Update Blynk dashboard
        Blynk.virtualWrite(VP_TEMPERATURE, currentTemperature);
        
        // Track max temperature
        if (currentTemperature > maxTempReached) {
            maxTempReached = currentTemperature;
        }
    }
    
    // ========================================
    // 2. SAFETY CHECK (HIGHEST PRIORITY)
    // ========================================
    handleSafetyCheck();
    
    // ========================================
    // 3. MODE EXECUTION
    // ========================================
    if (systemState == STATE_RUNNING && !isSafetyActive) {
        handleModeExecution();
    }
    
    // ========================================
    // 4. SUN TRACKING
    // ========================================
    if (systemState == STATE_RUNNING) {
        handleServoPositioning();
    }
    
    // ========================================
    // 5. DATA LOGGING
    // ========================================
    if (millis() - lastLogEntry >= LOG_INTERVAL) {
        lastLogEntry = millis();
        logData(currentTemperature, currentMode);
    }
    
    // ========================================
    // 6. UPDATE DASHBOARD
    // ========================================
    if (millis() % 10000 < 100) {  // Every 10 seconds
        updateBlynkDashboard();
    }
}

// ============================================================================
// SYSTEM SETUP FUNCTIONS
// ============================================================================

/**
 * Setup System - Initialize core components
 */
void setupSystem() {
    Serial.println("Initializing system...");
    
    // Initialize I2C
    Wire.begin();
    
    // Initialize SPI
    SPI.begin(SD_SCK, SD_MISO, SD_MOSI, SD_CS);
    
    // Initialize EEPROM (for storing settings)
    EEPROM.begin(512);
    
    // Set default target temperatures based on mode
    targetTemperature = 0;
    
    Serial.println("System initialized");
}

/**
 * Setup RTC - Initialize DS3231 Real-Time Clock
 */
void setupRTC() {
    Serial.println("Initializing RTC...");
    
    if (!rtc.begin()) {
        Serial.println("ERROR: Could not find RTC module!");
        Serial.println("Check I2C connections (SDA=GPIO21, SCL=GPIO22)");
        systemState = STATE_ERROR;
        return;
    }
    
    // Check if RTC lost power
    if (rtc.lostPower()) {
        Serial.println("RTC lost power - setting to compile time");
        rtc.adjust(DateTime(F(__DATE__), F(__TIME__)));
    }
    
    // Display current time
    DateTime now = rtc.now();
    Serial.print("RTC initialized: ");
    Serial.print(now.year());
    Serial.print("/");
    Serial.print(now.month());
    Serial.print("/");
    Serial.print(now.day());
    Serial.print(" ");
    Serial.print(now.hour());
    Serial.print(":");
    Serial.println(now.minute());
}

/**
 * Setup SD Card - Initialize MicroSD Card Storage
 */
void setupSDCard() {
    Serial.println("Initializing SD Card...");
    
    if (!SD.begin(SD_CS)) {
        Serial.println("WARNING: SD Card initialization failed!");
        Serial.println("Check connections (CS=GPIO5, SCK=GPIO18, MOSI=GPIO23, MISO=GPIO19)");
        isLogging = false;
        return;
    }
    
    // Check SD card type
    uint8_t cardType = SD.cardType();
    if (cardType == CARD_NONE) {
        Serial.println("WARNING: No SD card attached!");
        isLogging = false;
        return;
    }
    
    // Create session file
    String fileName = "/session_" + sessionID + ".csv";
    logFile = SD.open(fileName, FILE_WRITE);
    
    if (logFile) {
        // Write CSV header
        logFile.println("Timestamp,Temperature,Mode,SessionID");
        logFile.close();
        isLogging = true;
        Serial.println("SD Card initialized. Session file: " + fileName);
    } else {
        Serial.println("WARNING: Could not create log file!");
        isLogging = false;
    }
}

/**
 * Setup Servo - Initialize MG995 Servo Motor
 */
void setupServo() {
    Serial.println("Initializing Servo...");
    
    servoMotor.attach(SERVO_PIN);
    servoMotor.write(0);
    
    Serial.println("Servo initialized at 0°");
}

/**
 * Setup Blynk - Initialize Blynk IoT Platform
 */
void setupBlynk() {
    Serial.println("Connecting to WiFi...");
    
    WiFi.begin(ssid, password);
    
    int attempts = 0;
    while (WiFi.status() != WL_CONNECTED && attempts < 20) {
        delay(500);
        Serial.print(".");
        attempts++;
    }
    
    if (WiFi.status() == WL_CONNECTED) {
        Serial.println("\nWiFi connected!");
        Serial.print("IP Address: ");
        Serial.println(WiFi.localIP());
        
        Serial.println("Connecting to Blynk...");
        Blynk.config(auth);
        Blynk.connect();
        Serial.println("Blynk connected!");
    } else {
        Serial.println("\nWARNING: WiFi connection failed!");
        Serial.println("System will run in offline mode.");
    }
}

// ============================================================================
// MODE EXECUTION FUNCTIONS
// ============================================================================

/**
 * Handle Mode Execution - Execute the selected cooking mode
 */
void handleModeExecution() {
    // If no mode selected, do nothing
    if (currentMode == MODE_IDLE) {
        return;
    }
    
    // If system is in safety mode, prevent mode execution
    if (isSafetyActive) {
        return;
    }
    
    switch (currentMode) {
        case MODE_COOKING:
            // Cooking mode: Maintain 80-100°C
            targetTemperature = 90.0;  // Mid-range
            if (currentTemperature >= 100.0) {
                isHeating = false;
                sendNotification("Cooking temperature reached: " + String(currentTemperature) + "°C");
            } else if (currentTemperature < 80.0) {
                isHeating = true;
            }
            break;
            
        case MODE_STERILIZATION:
            // Sterilization mode: Maintain 120°C for 20 minutes
            targetTemperature = STERILIZATION_TEMP;
            
            if (!isSterilizing) {
                // Start sterilization process
                if (currentTemperature >= STERILIZATION_TEMP) {
                    startSterilization();
                } else {
                    isHeating = true;
                    sendNotification("Heating to 120°C for sterilization...");
                }
            } else {
                // Check if sterilization is complete
                checkSterilizationComplete();
            }
            break;
            
        case MODE_BOIL_WATER:
            // Boil water mode: Heat to 100°C and alert
            targetTemperature = BOIL_TEMP;
            
            if (currentTemperature >= BOIL_TEMP) {
                isHeating = false;
                sendNotification("Water is boiling! (100°C)");
                // Auto-switch to warming mode after boiling
                // currentMode = MODE_WARMING;
            } else {
                isHeating = true;
            }
            break;
            
        case MODE_WARMING:
            // Warming mode: Maintain 70°C
            targetTemperature = WARMING_TEMP;
            
            if (currentTemperature >= WARMING_TEMP + 5) {
                isHeating = false;
            } else if (currentTemperature < WARMING_TEMP - 5) {
                isHeating = true;
            }
            break;
            
        default:
            break;
    }
}

/**
 * Set Mode - Change the current cooking mode
 */
void setMode(int mode) {
    currentMode = mode;
    
    // Reset sterilization state
    isSterilizing = false;
    sterilizationStartTime = 0;
    
    // Set system state to running
    systemState = STATE_RUNNING;
    
    // Update target temperature based on mode
    switch (mode) {
        case MODE_COOKING:
            targetTemperature = 90.0;
            sendNotification("Cooking mode activated (80-100°C)");
            break;
        case MODE_STERILIZATION:
            targetTemperature = STERILIZATION_TEMP;
            sendNotification("Sterilization mode activated (120°C / 20 min)");
            break;
        case MODE_BOIL_WATER:
            targetTemperature = BOIL_TEMP;
            sendNotification("Boil water mode activated (100°C)");
            break;
        case MODE_WARMING:
            targetTemperature = WARMING_TEMP;
            sendNotification("Warming mode activated (70°C)");
            break;
        default:
            break;
    }
    
    Serial.print("Mode set to: ");
    Serial.println(getModeName(mode));
}

/**
 * Get Mode Name - Convert mode number to string
 */
String getModeName(int mode) {
    switch (mode) {
        case MODE_IDLE:          return "IDLE";
        case MODE_COOKING:       return "COOKING";
        case MODE_STERILIZATION: return "STERILIZATION";
        case MODE_BOIL_WATER:    return "BOIL_WATER";
        case MODE_WARMING:       return "WARMING";
        case MODE_SAFETY:        return "SAFETY";
        default:                 return "UNKNOWN";
    }
}

// ============================================================================
// SUN TRACKING FUNCTIONS
// ============================================================================

/**
 * Handle Servo Positioning - Move servo based on time
 */
void handleServoPositioning() {
    // Only move servo every SERVO_STEP_INTERVAL minutes
    if (millis() - lastServoMove < SERVO_STEP_INTERVAL * 60000) {
        return;
    }
    lastServoMove = millis();
    
    // Calculate sun angle
    float angle = calculateSunAngle();
    
    // Move servo to calculated angle
    moveServoToAngle(angle);
    
    Serial.print("Sun angle: ");
    Serial.print(angle);
    Serial.println("°");
}

/**
 * Calculate Sun Angle - Calculate solar angle based on RTC time
 * 
 * Formula: angle = (minutes_since_sunrise / total_daylight) × 120°
 * 
 * @return float Sun angle in degrees (0-120)
 */
float calculateSunAngle() {
    DateTime now = rtc.now();
    
    // Get current time in minutes from midnight
    int currentMinutes = now.hour() * 60 + now.minute();
    
    // Calculate minutes since sunrise
    int minutesSinceSunrise = currentMinutes - SUNRISE_TIME;
    
    // If before sunrise or after sunset, return 0 (idle position)
    if (minutesSinceSunrise < 0 || currentMinutes > SUNSET_TIME) {
        return 0;
    }
    
    // Calculate angle: (minutes_since_sunrise / total_daylight) × 120°
    float angle = ((float)minutesSinceSunrise / TOTAL_DAYLIGHT) * 120.0;
    
    // Clamp angle to valid range
    if (angle < 0) angle = 0;
    if (angle > 120) angle = 120;
    
    return angle;
}

/**
 * Move Servo to Angle - Position the servo at the given angle
 * 
 * @param angle Target angle in degrees (0-180)
 */
void moveServoToAngle(float angle) {
    // Clamp angle
    if (angle < 0) angle = 0;
    if (angle > 180) angle = 180;
    
    servoMotor.write((int)angle);
    delay(15);  // Allow servo to move
}

// ============================================================================
// TEMPERATURE FUNCTIONS
// ============================================================================

/**
 * Read Temperature - Read temperature from MAX6675 thermocouple
 * 
 * @return float Temperature in Celsius (-1 if error)
 */
float readTemperature() {
    float temp = thermocouple.readCelsius();
    
    // Check for sensor error
    if (isnan(temp) || temp < -10 || temp > 500) {
        Serial.println("WARNING: Temperature sensor error!");
        return currentTemperature;  // Return last valid reading
    }
    
    return temp;
}

// ============================================================================
// STERILIZATION FUNCTIONS
// ============================================================================

/**
 * Start Sterilization - Begin the sterilization hold cycle
 */
void startSterilization() {
    isSterilizing = true;
    sterilizationStartTime = millis();
    sendNotification("Sterilization started - holding 120°C for 20 minutes");
    Serial.println("Sterilization started - 20 minute hold");
}
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

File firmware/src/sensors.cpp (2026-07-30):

/*
 * ============================================================================
 * SOLARTRACE - Temperature Sensor Module Implementation
 * ============================================================================
 * 
 * File      : sensors.cpp
 * Purpose   : MAX6675 thermocouple temperature sensor implementation
 * Team      : South Sudan - UbuntuNet Alliance Women Hackathon 2026
 * ============================================================================
 */

#include "sensors.h"

// ============================================================================
// CONSTRUCTOR / DESTRUCTOR
// ============================================================================

TemperatureController::TemperatureController() {
    csPin = THERMO_CS;
    sckPin = THERMO_SCK;
    soPin = THERMO_SO;
    thermocouple = nullptr;
    isInitialized = false;
    currentTemperature = 0.0;
    lastValidTemperature = 0.0;
    offset = 0.0;
    minTemp = 1000.0;
    maxTemp = -1000.0;
    sumTemp = 0.0;
    sampleCount = 0;
    sensorReady = false;
    overheatDetected = false;
}

TemperatureController::~TemperatureController() {
    if (thermocouple != nullptr) {
        delete thermocouple;
        thermocouple = nullptr;
    }
}

// ============================================================================
// INITIALIZATION
// ============================================================================

void TemperatureController::begin() {
    begin(csPin, sckPin, soPin);
}

void TemperatureController::begin(int cs, int sck, int so) {
    csPin = cs;
    sckPin = sck;
    soPin = so;
    
    Serial.println("Initializing Temperature Sensor...");
    
    // Create thermocouple object
    thermocouple = new MAX6675(sckPin, csPin, soPin);
    
    if (thermocouple != nullptr) {
        isInitialized = true;
        
        // Test reading
        float testTemp = thermocouple->readCelsius();
        if (isValidTemperature(testTemp)) {
            sensorReady = true;
            currentTemperature = testTemp;
            lastValidTemperature = testTemp;
            Serial.print("Temperature sensor ready: ");
            Serial.print(testTemp);
            Serial.println("°C");
        } else {
            sensorReady = false;
            Serial.println("WARNING: Temperature sensor not responding!");
        }
    } else {
        Serial.println("ERROR: Failed to initialize thermocouple!");
        isInitialized = false;
    }
}

// ============================================================================
// CORE FUNCTIONS
// ============================================================================

float TemperatureController::readTemperature() {
    if (!isInitialized || thermocouple == nullptr) {
        return currentTemperature;
    }
    
    // Read temperature
    float temp = thermocouple->readCelsius();
    
    // Check for valid reading
    if (isValidTemperature(temp)) {
        currentTemperature = temp + offset;
        lastValidTemperature = currentTemperature;
        sensorReady = true;
        updateStatistics(currentTemperature);
        checkOverheat(currentTemperature);
    } else {
        sensorReady = false;
        currentTemperature = lastValidTemperature;
    }
    
    return currentTemperature;
}

float TemperatureController::getCurrentTemperature() {
    return currentTemperature;
}

float TemperatureController::getLastValidTemperature() {
    return lastValidTemperature;
}

// ============================================================================
// STATUS
// ============================================================================

bool TemperatureController::isSensorReady() {
    return sensorReady && isInitialized;
}

bool TemperatureController::isTemperatureValid() {
    return isValidTemperature(currentTemperature);
}

bool TemperatureController::isOverheatDetected() {
    return overheatDetected;
}

// ============================================================================
// CALIBRATION
// ============================================================================

void TemperatureController::calibrate() {
    if (!isInitialized) return;
    
    Serial.println("Calibrating temperature sensor...");
    
    // Take multiple readings for calibration
    float sum = 0.0;
    int count = 0;
    
    for (int i = 0; i < 10; i++) {
        float temp = thermocouple->readCelsius();
        if (isValidTemperature(temp)) {
            sum += temp;
            count++;
        }
        delay(100);
    }
    
    if (count > 0) {
        float avg = sum / count;
        Serial.print("Average reading: ");
        Serial.print(avg);
        Serial.println("°C");
        Serial.print("Current offset: ");
        Serial.println(offset);
    }
}

void TemperatureController::setOffset(float off) {
    offset = off;
    Serial.print("Temperature offset set to: ");
    Serial.println(offset);
}

float TemperatureController::getOffset() {
    return offset;
}

// ============================================================================
// STATISTICS
// ============================================================================

float TemperatureController::getMinTemperature() {
    return (minTemp == 1000.0) ? 0.0 : minTemp;
}

float TemperatureController::getMaxTemperature() {
    return (maxTemp == -1000.0) ? 0.0 : maxTemp;
}

float TemperatureController::getAverageTemperature() {
    return (sampleCount == 0) ? 0.0 : (sumTemp / sampleCount);
}

void TemperatureController::resetStatistics() {
    minTemp = 1000.0;
    maxTemp = -1000.0;
    sumTemp = 0.0;
    sampleCount = 0;
    Serial.println("Temperature statistics reset");
}

// ============================================================================
// DEBUG
// ============================================================================

void TemperatureController::printStatus() {
    Serial.println("=== Temperature Sensor Status ===");
    Serial.print("Initialized: ");
    Serial.println(isInitialized ? "YES" : "NO");
    Serial.print("Sensor Ready: ");
    Serial.println(sensorReady ? "YES" : "NO");
    Serial.print("Current Temp: ");
    Serial.print(currentTemperature);
    Serial.println("°C");
    Serial.print("Last Valid: ");
    Serial.print(lastValidTemperature);
    Serial.println("°C");
    Serial.print("Overheat: ");
    Serial.println(overheatDetected ? "YES" : "NO");
    Serial.println("==================================");
}

void TemperatureController::printStatistics() {
    Serial.println("=== Temperature Statistics ===");
    Serial.print("Samples: ");
    Serial.println(sampleCount);
    Serial.print("Min: ");
    Serial.print(getMinTemperature());
    Serial.println("°C");
    Serial.print("Max: ");
    Serial.print(getMaxTemperature());
    Serial.println("°C");
    Serial.print("Avg: ");
    Serial.print(getAverageTemperature());
    Serial.println("°C");
    Serial.println("================================");
}
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

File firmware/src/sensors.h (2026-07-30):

/*
 * ============================================================================
 * SOLARTRACE - Temperature Sensor Module Header
 * ============================================================================
 * 
 * File      : sensors.h
 * Purpose   : MAX6675 thermocouple temperature sensor interface
 * Team      : South Sudan - UbuntuNet Alliance Women Hackathon 2026
 * ============================================================================
 */

#ifndef SENSORS_H
#define SENSORS_H

#include <Arduino.h>
#include <MAX6675.h>

// ============================================================================
// PIN DEFINITIONS
// ============================================================================

#define THERMO_CS    15       // GPIO15 - Chip Select
#define THERMO_SCK   14       // GPIO14 - SPI Clock
#define THERMO_SO    12       // GPIO12 - SPI Data Out

// ============================================================================
// TEMPERATURE CONSTANTS
// ============================================================================

#define TEMP_READ_INTERVAL    500    // Milliseconds between readings
#define MAX_SAFE_TEMP         130.0  // Maximum safe temperature
#define MIN_VALID_TEMP        -10.0  // Minimum valid temperature
#define MAX_VALID_TEMP        500.0  // Maximum valid temperature

// ============================================================================
// TEMPERATURE CONTROLLER CLASS
// ============================================================================

class TemperatureController {
public:
    // Constructor / Destructor
    TemperatureController();
    ~TemperatureController();
    
    // Initialization
    void begin();
    void begin(int csPin, int sckPin, int soPin);
    
    // Core Functions
    float readTemperature();
    float getCurrentTemperature();
    float getLastValidTemperature();
    
    // Status
    bool isSensorReady();
    bool isTemperatureValid();
    bool isOverheatDetected();
    
    // Calibration
    void calibrate();
    void setOffset(float offset);
    float getOffset();
    
    // Statistics
    float getMinTemperature();
    float getMaxTemperature();
    float getAverageTemperature();
    void resetStatistics();
    
    // Debug
    void printStatus();
    void printStatistics();
    
private:
    // Internal Components
    MAX6675* thermocouple;
    int csPin;
    int sckPin;
    int soPin;
    bool isInitialized;
    
    // Current Values
    float currentTemperature;
    float lastValidTemperature;
    float offset;
    
    // Statistics
    float minTemp;
    float maxTemp;
    float sumTemp;
    int sampleCount;
    
    // Status
    bool sensorReady;
    bool overheatDetected;
    
    // Internal Methods
    bool isValidTemperature(float temp);
    void updateStatistics(float temp);
    void checkOverheat(float temp);
    float clampTemperature(float temp);
};

#endif // SENSORS_H

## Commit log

2026-07-30 firmware for SolarTrace smart solar cooker, by: Alek
    This firmware implements a smart solar cooker with automatic sun tracking using an ESP32 microcontroller, supporting multiple cooking modes and remote monitoring via Blynk.
2026-07-30 Add Sun Tracking Module Implementation, By: Alek
    Implement sun tracking algorithm with RTC integration and servo control.
2026-07-30 Add temperature sensor module implementation, By: Alek
    Implement MAX6675 thermocouple temperature sensor functionality with initialization, calibration, and statistics tracking.
2026-07-30 Add sensors.h for MAX6675 temperature sensor interface, By: Alek
    This header file defines the interface for the MAX6675 thermocouple temperature sensor, including pin definitions, temperature constants, and the TemperatureController class with its methods.
2026-07-31 Add bill of materials for hardware components, Alek
    Added detailed bill of materials for hardware components including categories, items, models, quantities, costs, suppliers, and notes.
    [bill_of_materials.csv]
2026-07-31 Update descriptions and quantities in BOM, Alek
    [bill_of_materials.csv]
2026-07-31 Remove total cost line from bill of materials
    Removed total cost line from bill of materials.
    [bill_of_materials.csv]
2026-07-31 Document ESP32 pin configuration for SolarTrace
    Added detailed pin configuration for SolarTrace ESP32, including pin mapping, function grouping, pull-up resistor configuration, voltage level compatibility, and pin usage summary.
2026-07-31 Update pin configuration diagrams and details
2026-07-31 Initialize SolarTrace dashboard configuration
    Added configuration for SolarTrace project including dashboard layout, widgets, and automations for temperature alerts.
2026-08-15 Add Week 4 Progress Report for SolarTrace project
    This report outlines the progress made during Week 4 of the SolarTrace project, including component testing results, sensor calibration, and software development updates.
2026-08-24 Create Week 5 Progress Report for SolarTrace project
    Added Week 5 Progress Report detailing project milestones, hardware assembly, software upgrades, and hackathon submissions.
